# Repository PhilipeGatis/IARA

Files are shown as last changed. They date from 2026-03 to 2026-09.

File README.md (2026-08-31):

<p align="center">
  IARA Logo
</p>

# IARA

**Automated Water Change, Fertilization & Filtration System for Aquariums** — ESP32 firmware.

*Named after Iara, the freshwater spirit from Brazilian folklore.*



> 🇧🇷 Leia em português: [README.pt-BR.md](README.pt-BR.md)
>
> 🇯🇵 日本語で読む: [README.ja.md](README.ja.md)

---

## 📖 About

**IARA** is a complete embedded system for planted aquarium automation. It manages:

- **Water Change (TPA)** — automated drain & refill with a 6-state state machine.
- **Fertilization** — scheduled dosing via peristaltic pumps with stock tracking.
- **Filtration** — canister on/off control through an SSR relay (AC power), with a timed pause for feeding.
- **Safety** — continuous sensor monitoring, watchdog timer, and emergency shutdown mode.

The firmware runs on an **ESP32 DevKit V1** and features an **embedded web dashboard** (React + Vite served via LittleFS), **color TFT display (ST7735)**, **DS3231 RTC clock**, and a **serial command interface**.
You can easily access the web interface on your local network by navigating to **http://iara.local** (via mDNS), without needing to find the ESP32's IP address.

---

## 📱 Interface

The dashboard is served from the ESP32 itself over LittleFS — no cloud, no
account, no external dependency. It is mobile-first, since the phone is what
you have in your hand when you are standing at the tank.

| | | |
|---|---|---|
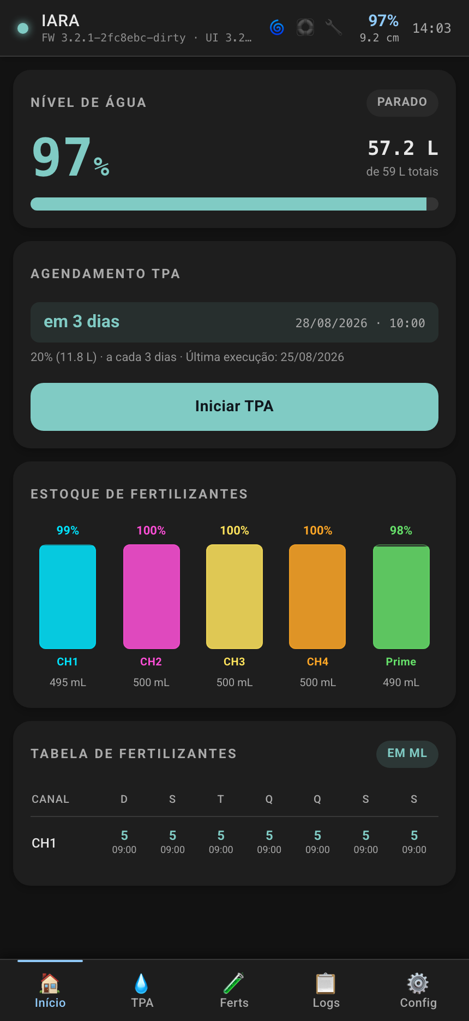
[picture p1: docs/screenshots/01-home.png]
Home
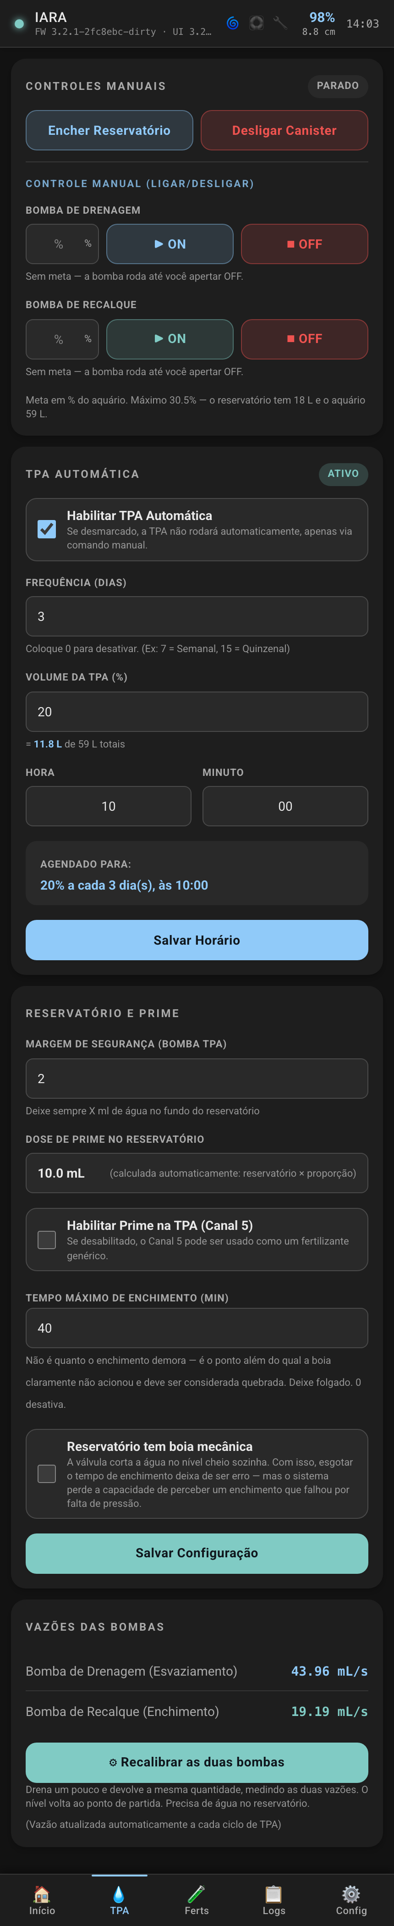
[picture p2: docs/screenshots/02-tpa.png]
Water change
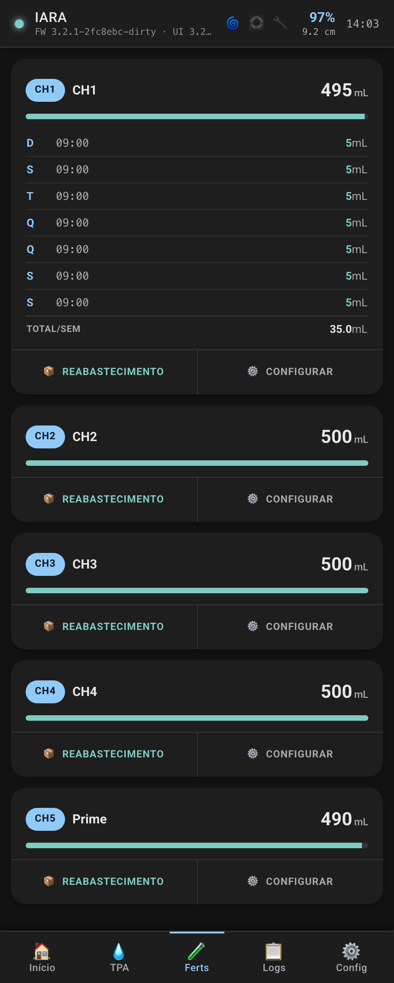
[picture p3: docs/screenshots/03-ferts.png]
Fertilizers
|  |  |  |
| **Home** — level, next change, fertilizer stock | **Water change** — manual pumps, schedule, calibration | **Fertilizers** — per-channel weekly dosing |

| | |
|---|---|
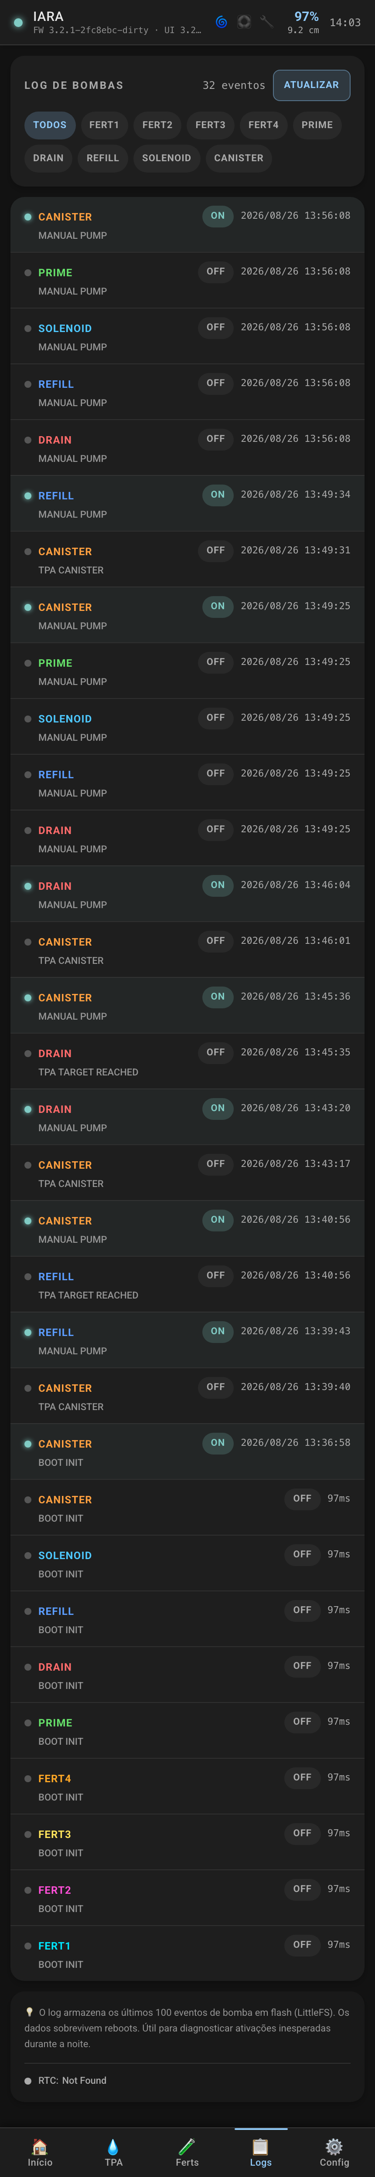
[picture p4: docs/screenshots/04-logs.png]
Logs
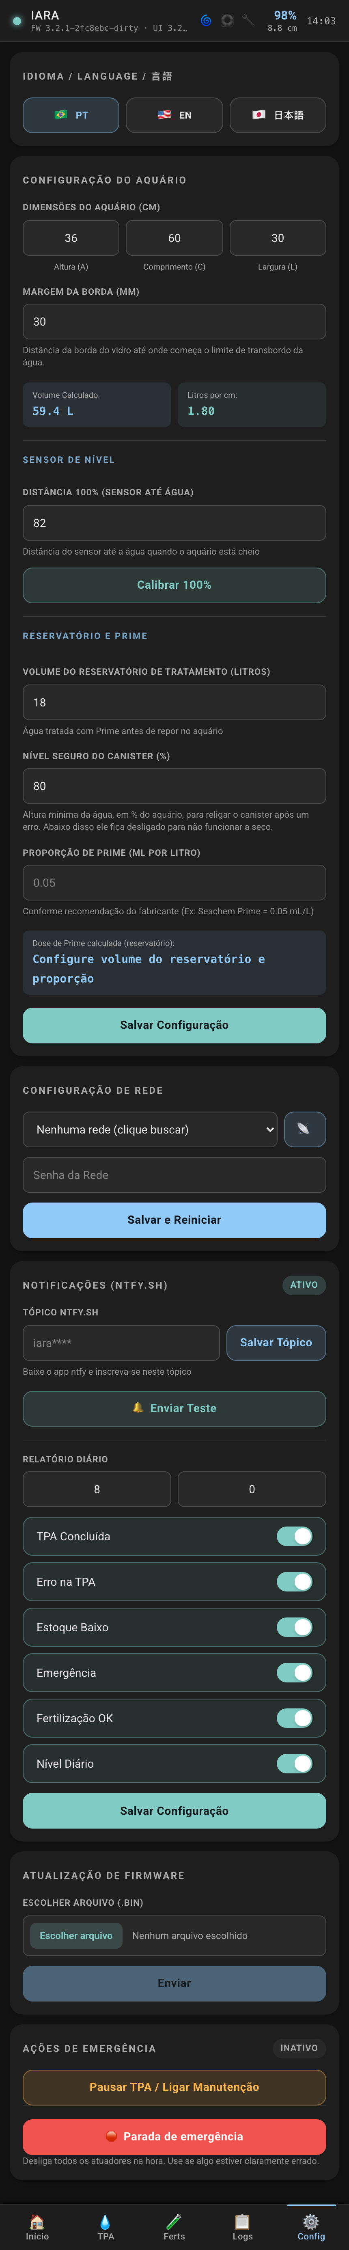
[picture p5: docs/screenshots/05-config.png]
Config
|  |  |
| **Logs** — every pump activation with its reason | **Config** — geometry, sensor, network, notifications, OTA |

---

## 📚 Additional Documentation

The project includes detailed hardware documentation in the following files:

| Document | Description |
|---|---|
| [`BOM.en.md`](BOM.en.md) | **Bill of Materials** — complete list of all components required for assembly, organized by layer (AC, DC, actuators, sensors, protection, and connectors), with specifications and quantities. |
| [`HARDWARE.en.md`](HARDWARE.en.md) | **Hardware Architecture** — detailed technical documentation with wiring diagrams for each layer (AC input, DC bus, and peripherals), including noise protection schemes, the 10 kΩ pull-up on the ultrasonic UART line, and safety implementation notes. |
| [`3d_models/`](3d_models/) | **3D Models (OpenSCAD)** — parametric electronics enclosure (`electronics_enclosure.scad`) with full module layout, dosing pump supports (`dosing_pump_support.scad` / `dosing_pump_single.scad`), and drill test plate for verification. |

---

## 🏗️ Firmware Architecture

```
main.cpp               ← Main orchestrator
├── SafetyWatchdog      ← Sensors + emergency + maintenance mode
├── TimeManager         ← DS3231 RTC + NTP sync
├── FertManager         ← Dosing + NVS dedup + stock tracking
├── WaterManager        ← Water change state machine (6 states)
├── DisplayManager      ← TFT ST7735 128×160 (SPI)
└── WebManager          ← Embedded web dashboard + serial interface
```

### Safety-First Loop

```cpp
loop() {
    safety.update();          // 🔴 Highest priority
    if (emergency) return;
    timeMgr.update();
    commands.process();
    schedules.check();
    waterMgr.update();        // Water change state machine
    telemetry.send();
}
```

### 🔄 Water Change (TPA) Flow

The TPA is a 6-state state machine that runs non-blocking inside the main loop. Each state has a configurable timeout for safety.

```mermaid
stateDiagram-v2
    [*] --> FILLING_RESERVOIR: startTPA()
    FILLING_RESERVOIR --> DOSING_PRIME: float switch
    DOSING_PRIME --> CANISTER_OFF: 2s mix
    CANISTER_OFF --> DRAINING: 3s settle
    DRAINING --> REFILLING: level reached
    REFILLING --> CANISTER_ON: level reached
    CANISTER_ON --> [*]: COMPLETE

    DRAINING --> ERROR: timeout
    FILLING_RESERVOIR --> ERROR: timeout
    REFILLING --> ERROR: timeout
    ERROR --> [*]: check level → canister ON/OFF
```

| Step | State | What happens |
|---|---|---|
| 1 | **FILLING_RESERVOIR** | Solenoid valve opens to fill the reservoir with tap water. The float switch closes it when full. If the reservoir is already full the step is skipped without opening the valve. |
| 2 | **DOSING_PRIME** | Peristaltic pump doses dechlorinator (Prime) into the reservoir. Waits 2 seconds for mixing. Stock is deducted and saved to NVS. |
| 3 | **CANISTER_OFF** | Canister filter is turned off (SSR relay HIGH). Waits 3 seconds for the water to settle so the ultrasonic gets a stable reading. |
| 4 | **DRAINING** | Drain pump turns on. The ultrasonic monitors the level and the pump runs until the target is reached. Flow rate is measured for auto-calibration. |
| 5 | **REFILLING** | Refill pump turns on, pumping treated water from the reservoir into the aquarium. When the original level appears reached the pump **pauses for 3 seconds** and confirms on a settled surface — inflow beside the sensor reads as a level higher than the tank holds. If the calm reading is still short, it resumes. A reed switch in series with the MOSFET channel signal cuts the pump in hardware should max level be reached. Flow rate is measured for calibration. |
| 6 | **CANISTER_ON** | Canister filter is turned back on. **TPA cycle complete.** Calibrated flow rates are saved to NVS for the next TPA. |

> **Why the reservoir comes first:** everything that can fail there — no mains pressure, a stuck float, a dead solenoid — fails while the aquarium is still full and the filter still running. Draining first would leave the same failure with a low tank, a stopped canister and no treated water to put back.

**Safety at every step:**
- Each state has a **dynamic timeout** calculated from calibrated flow rates (`volume / flow × 1.5`). First TPA uses safe defaults: **30s drain, 15s refill**.
- A **reed switch** in series with the signal wire between GPIO33 and MOSFET module input IN7 cuts the refill pump at max level, **independently of the firmware** — it works with the ESP32 hung or the ultrasonic silent. See [`HARDWARE.en.md`](HARDWARE.en.md).
- **Emergency abort** at any point turns off all actuators and restores the canister filter.
- **On error**, the system checks the water level via ultrasonic before turning the canister back on. If the level is too low (e.g. error during drain), the canister **stays OFF** to avoid running dry and damaging the pump.

---

## 🔌 Hardware Overview

### Main Connections

```mermaid
graph LR
  subgraph Power [⚡ 12V & 5V]
    PSU[12V PSU] -->|12V| MOSFET[8-Channel MOSFET Module]
    PSU -->|12V| LM2596[LM2596 Step Down]
    LM2596 -->|5V| Cap[Electrolytic Capacitor]
    Cap -->|5V| ESP32[ESP32 VIN]
    ESP32 -->|3.3V VCC| SENS[Sensors]
  end

  subgraph Signals [🎮 ESP32 Signals]
    ESP32 -->|D21 SDA, D22 SCL| I2C[RTC DS3231]
    ESP32 -->|SPI D15,16,17,23| TFT[TFT Display ST7735]
    ESP32 -->|D12, D13, D14, D25-D27, D32, D33| MOSFET
    ESP32 -->|D2| SSR[Omron SSR]
    ESP32 ---|D34 RX| Ultra[Ultrasonic A02YYUW UART]
    ESP32 ---|D5| Button[Panel button]
    ESP32 ---|D19| Float[Float Switch]
  end

  MOSFET -->|OUT 1–5| Peristaltic[5x Peristaltic Pumps]
  MOSFET -->|OUT 6| Drain[Drain Pump]
  MOSFET -->|OUT 7| Refill[Refill Pump]
  MOSFET -->|OUT 8| Solenoid[Solenoid Valve]
```

> For detailed wiring diagrams and protection notes (flyback diodes, star GND), see [`HARDWARE.en.md`](HARDWARE.en.md).
>
> For the complete component list and quantities, see [`BOM.en.md`](BOM.en.md).

### ESP32 GPIO Connection Diagram

| GPIO | Function | Component | Direction | Protocol |
|---|---|---|---|---|
| **D2** | Canister ON/OFF | Omron SSR Relay | Output | Digital |
| **D12** | Fertilizer CH2 | MOSFET channel 2 | Output | Digital |
| **D13** | Fertilizer CH1 | MOSFET channel 1 | Output | Digital |
| **D14** | Fertilizer CH3 | MOSFET channel 3 | Output | Digital |
| **D15** | TFT CS | ST7735 Display (CS) | Output | SPI (CS) |
| **D16** | TFT SCK | ST7735 Display (SCK) | Output | SPI (SCK) |
| **D17** | TFT A0 (Data/Command) | ST7735 Display (A0) | Output | SPI (DC) |
| **D5** | Navigation button | Push/Tactile Button (Panel) | Input (PULLUP) | Digital |
| **D18** | Ultrasonic control lead | A02YYUW (control wire) | Output | Held idle-high |
| **D19** | Reservoir float | Horizontal Float Switch | Input (PULLUP) | Digital |
| **D21** | SDA | DS3231 RTC | Bidirectional | I2C |
| **D22** | SCL | DS3231 RTC | Bidirectional | I2C |
| **D23** | TFT SDA (Data) | ST7735 Display (SDA) | Output | SPI (MOSI) |
| **D25** | Drain pump | MOSFET channel 6 | Output | Digital |
| **D26** | Prime (dechlorinator) | MOSFET channel 5 | Output | Digital |
| **D27** | Fertilizer CH4 | MOSFET channel 4 | Output | Digital |
| **D32** | Solenoid valve | MOSFET channel 8 | Output | Digital |
| **D33** | Refill pump | MOSFET channel 7 | Output | Digital |
| **D34** | Ultrasonic UART RX | A02YYUW | Input | Digital (Connect to Sensor TX) |
| **VIN** | 5V Power | LM2596 step-down | — | Power |
| **EN** | Shared reset | ST7735 Display (RESET) | — | Reset |
| **3.3V** | Backlight | ST7735 Display (LED) | — | Power |

---

## 🛡️ Safety & Reliability

The system is designed with a **safety-first** approach to prevent flooding, equipment damage, and fish loss.

### Software Protections

| Protection | Description |
|---|---|
| **Max-level interlock (hardware)** | Reed switch in series with the refill channel's signal. Cuts the pump without involving the firmware. It is the only protection that survives a hung ESP32. |
| **SafetyWatchdog** | Runs at highest priority every loop iteration. Monitors the ultrasonic, detects emergency conditions, and shuts down all actuators. Counts 10 consecutive overflow readings before flagging, to prevent false positives. |
| **Non-blocking loops** | All wait states (canister settle, prime mixing) use `millis()` instead of `delay()`, so the safety watchdog keeps running during waits. |
| **State machine timeouts** | Each TPA state (`DRAINING`, `FILLING`, `REFILLING`) has a configurable timeout. Exceeding it triggers an error state and shuts down all actuators. |
| **NVS deduplication** | Prevents double-dosing fertilizers on the same day, even after unexpected reboots. |
| **Emergency shutdown** | `emergency_stop` command turns off ALL actuators immediately. |
| **CPU throttle** | Main loop runs at ~100 Hz (`delay(10)`), preventing overheating and leaving CPU headroom for WiFi/TCP stack. |
| **Pump auto-calibration** | Flow rates measured inline during TPA (Δlevel × litersPerCm / Δtime). Dynamic timeouts = `(volume / flow) × 1.5`. First TPA uses safe 30s/15s defaults. |
| **Mandatory TPA config** | TPA will not start unless all required parameters are configured: aquarium dimensions, reservoir volume, drain %, and canister safe level %. Prevents running with invalid/default values. |
| **Canister safe level (%)** | Configurable minimum water level (as % of aquarium height) required to safely turn the canister back on after a TPA error. If the water is below this threshold (e.g. error during drain), the canister stays OFF to prevent running dry. |

### Hardware Recommendations

| Protection | Description |
|---|---|
| **Max-level reed switch** | NO (normally open) reed with a magnet held at the max water level by an EVA float, wired in series with the **signal** wire between GPIO33 and MOSFET input IN7 — never in series with the pump's power. Cuts the pump physically if water rises too high, independent of firmware. See [`HARDWARE.en.md`](HARDWARE.en.md). |
| **Flyback diodes** | FR154 on pumps, 1N5822 on solenoid — absorb voltage spikes from inductive loads. |
| **Decoupling capacitors** | 1000µF near ESP32, 470µF near MOSFET module — absorb brownout transients. |
| **Direct 3.3V UART** | A02YYUW powered at 3.3V connects directly to ESP32 without voltage dividers. |
| **Siphon break (Drain)** | Wire a solenoid valve in parallel with the drain pump (requires its own flyback diode) or make a small breather hole in the hose inside the aquarium to prevent water from continuing to drain by gravity after the pump turns off. |

---

## 📲 Push Notifications

IARA sends real-time push notifications to your phone via [ntfy.sh](https://ntfy.sh/). Each notification type can be individually enabled or disabled via the dashboard.

### Notification Types

| Type | Trigger | Example Message |
|---|---|---|
| **TPA Complete** | Water change finished successfully | `✅ TPA completed successfully` |
| **TPA Error** | Timeout or failure during TPA | `⚠️ Drain timeout \| Canister: OFF (nivel 45%, min: 60%)` |
| **Fert Low Stock** | Fertilizer stock below threshold | `⚠️ CH1 Potássio: 15 mL remaining (threshold: 50 mL)` |
| **Emergency** | Emergency shutdown triggered | `🚨 Emergency shutdown activated!` |
| **Fert Complete** | Fertilizer dose completed | `💧 CH2 dosed 5.0 mL` |
| **Daily Level** | Scheduled daily water level report | `📊 Water level: 12.3 cm` |

### Rate Limiting

| Parameter | Value |
|---|---|
| Cooldown per type | 5 minutes (same type won't fire twice) |
| Max per day | 20 notifications total |
| Daily counter reset | Midnight (auto) |

### Setup

1. Download the **ntfy** app on your phone (iOS/Android)
2. Tap "+" to "Subscribe to topic"
3. Enter the topic generated by IARA (shown on the aquarium display or Dashboard) and you're done!
3. Or set the topic from the IARA dashboard (`Notifications → ntfy.sh Topic`), or via API:
   ```bash
   curl -X POST http://<ESP32_IP>/api/notify/key -d '{"topic":"YOUR_TOPIC"}'
   ```
4. Enable/disable specific notification types via the dashboard

---

## ⚙️ System Configuration

Before the first TPA can run, the system requires all safety-critical parameters to be configured. This ensures the water change operates safely for your specific aquarium setup.

### Required Parameters (Mandatory for TPA)

| Parameter | API Field | Description |
|---|---|---|
| **Aquarium Height** | `aqHeight` | Internal height in cm |
| **Aquarium Length** | `aqLength` | Internal length in cm |
| **Aquarium Width** | `aqWidth` | Internal width in cm |
| **Reservoir Volume** | `reservoirVolume` | Reservoir capacity in liters |
| **TPA Drain %** | `tpaPercent` | Percentage of aquarium volume to drain (e.g. 30%) |
| **Canister Safe Level %** | `canisterSafePct` | Minimum water % required to safely turn canister ON (e.g. 60%) |

> [!IMPORTANT]
> TPA will **not start** until all 6 parameters above are configured. The dashboard shows `tpaConfigReady: true/false` to indicate readiness.

### Optional Parameters

| Parameter | API Field | Description |
|---|---|---|
| **Water Margin** | `aqMarginMm` | Distance from top edge to the overflow limit (mm) |
| **Prime Ratio** | `primeRatio` | mL of dechlorinator per liter of water |
| **Reservoir Safety** | `reservoirSafetyML` | Minimum mL to keep in reservoir for pump safety |
| **TPA Interval** | `tpaInterval` | Days between automatic TPAs (e.g. 7) |
| **TPA Schedule** | `tpaHour`, `tpaMinute` | Time of day for automatic TPA |

### Configuration via API

**Aquarium dimensions:**
```bash
curl -X POST http://<ESP32_IP>/api/config/aquarium \
  -H "Content-Type: application/json" \
  -d '{"aqHeight":45, "aqLength":90, "aqWidth":40, "aqMarginMm":30, "reservoirVolume":20, "primeRatio":0.025}'
```

**TPA schedule + canister safety:**
```bash
curl -X POST http://<ESP32_IP>/api/schedule \
  -H "Content-Type: application/json" \
  -d '{"tpaInterval":7, "tpaHour":10, "tpaMinute":0, "tpaPercent":30, "canisterSafePct":60}'
```

### How Configuration is Stored

All parameters are persisted in **NVS (Non-Volatile Storage)** and survive reboots and power cycles. Configuration can be set via:

1. **Web Dashboard** — React SPA with forms for all parameters
2. **REST API** — JSON endpoints for programmatic access
3. **Serial Commands** — USB serial for debugging and initial setup

### Derived Values (Auto-Calculated)

| Value | Formula | Purpose |
|---|---|---|
| **Aquarium Volume** | `(Height - Margin) × Length × Width / 1000` | Total water volume in liters |
| **Liters per cm** | `Length × Width / 1000` | Volume change per cm of water level |
| **Prime dose** | `Reservoir Volume × Prime Ratio` | Auto-calculated dechlorinator dose |
| **Drain cm** | `(Volume × TPA%) / Liters per cm` | Calculated at TPA start |
| **Canister safe cm** | `EffHeight × (100 - SafePct) / 100` | Ultrasonic distance threshold |
| **Dynamic timeouts** | `(Volume / Flow) × 1.5` | Calculated from calibrated flow rates |

---

---

## 🧪 Testing

### Run unit tests (no hardware required)

```bash
pio test -e native
```

### Generate coverage report

```bash
pio test -e coverage && ./scripts/coverage.sh
open coverage/index.html
```

### Test Suites

| Suite | Tests | Coverage |
|---|---|---|
| `test_fert_manager` | 13 | NVS dedup, stock, GPIO, persistence |
| `test_safety_watchdog` | 14 | Sensors, emergency, maintenance |
| `test_water_manager` | 23 | Full water change state machine + calibration |
| `test_time_manager` | 15 | DateTime, scheduling, formatting |
| `test_notify_manager` | 10 | Notifications, formatting |

### 📊 Code Coverage

| File | Coverage |
|---|---|
| `WaterManager.cpp` | 92% |
| `SafetyWatchdog.cpp` | 81% |
| `FertManager.cpp` | 75% |
| `NotifyManager.cpp` | 43% |
| **Total** | **75%** |

> 75 native unit tests running in CI on every commit.

---

## 🚀 Build & Deploy

### First-time setup — WiFi credentials

Credentials live outside the repository. Before the first build:

```bash
cp secrets.ini.example secrets.ini
# then edit secrets.ini with your network's SSID and password
```

`secrets.ini` is gitignored, so it never reaches the repository. The build fails
without it.

### Build and flash firmware

```bash
# Build firmware
pio run

# Flash to ESP32
pio run --target upload

# Serial monitor
pio device monitor
```

### Full deploy (Frontend + Firmware)

The `Makefile` automates the full workflow:

```bash
# All at once: build React → upload LittleFS → flash firmware
make all

# Or individual steps:
make build-front     # Build React app (Vite)
make upload-fs       # Upload static files to LittleFS
make upload-fw       # Build and flash C++ firmware
make monitor         # Open serial monitor
make clean           # Clean all builds
```

### Frontend (Web Dashboard)

The web dashboard is a React + Vite + Tailwind CSS SPA located in `frontend/`. After building, static files are copied to `data/` and uploaded to the ESP32 via LittleFS.

```bash
cd frontend && npm install && npm run build
```

---

## ⌨️ Serial Commands

| Command | Description |
|---|---|
| `help` | List available commands |
| `status` | Current system state |
| `tpa` | Start manual water change |
| `abort` | Abort water change in progress |
| `maint` | Toggle maintenance mode (30 min) |
| `fert_time HH MM` | Set fertilization time |
| `tpa_interval DAYS` | Set days between automatic water changes (0 = off) |
| `dose CH ML` | Set dose for channel CH (1–5) |
| `reset_stock CH ML` | Reset stock for channel CH |
| `set_drain CM` | Set drain target level |
| `set_refill CM` | Set refill target level |
| `emergency_stop` | Shut down ALL actuators |

---

## 📁 Project Structure

```
├── BOM.md                    # Bill of Materials (pt-BR)
├── BOM.en.md                 # Bill of Materials (en-US)
├── BOM.ja.md                 # Bill of Materials (ja-JP)
├── HARDWARE.md               # Hardware architecture (pt-BR)
├── 3d_models/                # 3D models for printing and laser cutting
│   ├── electronics_enclosure.scad  # Electronics enclosure (base + lid)
│   ├── dosing_pump_support.scad    # 8-pump dosing support
│   └── dosing_pump_single.scad     # Single pump support
├── HARDWARE.en.md            # Hardware architecture (en-US)
├── HARDWARE.ja.md            # Hardware architecture (ja-JP)
├── README.md                 # Documentation (en-US) — default
├── README.pt-BR.md           # Documentation (pt-BR)
├── README.ja.md              # Documentation (ja-JP)
├── Makefile                  # Automation: build frontend + upload
├── platformio.ini            # Environments: esp32dev, native, coverage
├── include/
│   ├── Config.h              # Pins, timeouts, constants
│   ├── SafetyWatchdog.h
│   ├── TimeManager.h
│   ├── FertManager.h
│   ├── WaterManager.h
│   ├── WebManager.h
│   └── web_dashboard.h       # Dashboard HTML/CSS/JS (fallback)
├── src/
│   ├── main.cpp              # Setup + loop
│   ├── SafetyWatchdog.cpp
│   ├── TimeManager.cpp
│   ├── FertManager.cpp
│   ├── WaterManager.cpp
│   └── WebManager.cpp
├── frontend/                 # React + Vite + Tailwind dashboard
│   ├── src/
│   └── vite.config.ts
├── data/                     # Static files (frontend build → LittleFS)
├── test/
│   ├── mocks/                # Arduino mock layer (GPIO, NVS, RTC)
│   ├── test_fert_manager/
│   ├── test_safety_watchdog/
│   ├── test_water_manager/
│   └── test_time_manager/
├── scripts/
│   └── coverage.sh           # lcov coverage report generator
└── .github/workflows/
    └── test.yml              # CI: tests on every commit
```

---

## ☕ Support

If you find this project helpful, consider buying me a coffee!

<a href="https://buymeacoffee.com/iara.automatedwaterchange" target="_blank">
  Buy Me A Coffee
</a>

---

## 📜 License

MIT

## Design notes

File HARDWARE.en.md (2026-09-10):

# Hardware Architecture Documentation: Aquarium Management System

## 📋 Overview

The system uses a **Defense in Depth** topology with noise filtering at the input (AC), stabilization on the main bus (DC), and inductive spike suppression at the edge (Actuators).

```
┌─────────────────────┐     ┌─────────────────────┐     ┌─────────────────────┐
│  LAYER 1: AC        │ ──► │  LAYER 2: DC        │ ──► │  LAYER 3: EDGE      │
│  Input/Protection   │     │  Bus/Logic          │     │  Peripherals/Suppr. │
│                     │     │                     │     │                     │
│  • AC Fuse          │     │  • 12.53V PSU       │     │  • Flyback Diodes   │
│  • NTC (Inrush)     │     │  • LM2596 → 5.1V    │     │  • Decoupling Caps  │
│  • EMI Filter (Y)   │     │  • Cap Bank         │     │  • Sensors (GX12)   │
│  • Canister Relay   │     │  • 8-Ch MOSFET      │     │  • Pumps + Valve    │
└─────────────────────┘     └─────────────────────┘     └─────────────────────┘
```

---

## ⚡ Layer 1: AC Input & Protection (Infrastructure)

The power input architecture focuses on simplicity and maximum electrical safety, delegating heavy filtering (like EMI filter and NTC/Inrush limits) to the professional circuits already built into the Switching Power Supply.

### Components

| Component | Function |
|---|---|
| **AC Glass Fuse** (3A to 5A) | Mandatory item: Protection against hard short circuits and fire risks |
| **SSR Relay Module 1CH** | Independent control via ESP32 for the Canister filter (AC) |

### Wiring Diagram

<p align="center">
  AC input: IEC C14 inlet splitting earth, neutral and live; live passes through the fuse and the SSR relay before the canister socket.
</p>

---

## 🔋 Layer 2: DC Bus & Logic (Distribution)

Responsible for converting power to logic levels and maintaining ESP32 stability during heavy load switching.

### Components

| Component | Function |
|---|---|
| **180W Switching PSU** | Adjusted to 12.53V |
| **T5AL250V Fuse** | Physical firewall for 8 pumps and sensors |
| **LM2596** | Step-down adjusted to 5.1V (ESP32 power) |
| **1× 470µF 16V** | In parallel at 12V MOSFET input (Prevents voltage dips on pump startup) |
| **4× 1000µF 10V** | In parallel at 5V output (Acts as a "UPS" for ESP32 to withstand line fluctuations and spikes) |
| **1× 1000µF 10V** | Directly across the devkit's 3V3 and GND pins. The 5V bank does **not** cover this node — see the warning below |

### Wiring Diagram

<p align="center">
  DC bus: the 12.53 volt supply feeding the LM2596 and the MOSFET module, with every power return starred at the V minus terminal.
</p>

> [!IMPORTANT]
> **POWER GND — star at the PSU**: **Power** negative references (MOSFET module, LM2596, pumps, solenoid) must return directly to the PSU V− terminal, to avoid ground loops.

> [!CAUTION]
> **SIGNAL GND — the opposite rule**: The return (GND) of the **sensors** — float switch and ultrasonic — must go to the **ESP32 GND pin**, and **never** straight to the PSU terminal.
>
> The ESP32 measures every input relative to *its own* GND pin. A sensor referenced to the PSU terminal hands the GPIO the potential difference between those two points. During pump startup that difference exceeds **1 V negative** — far beyond the ESP32's −0.3 V absolute minimum — and the damage accumulates until the pin fails open.
>
> This is exactly how GPIO5 and GPIO19 burned out. See [`PROTECAO_ELETRICA.md`](PROTECAO_ELETRICA.md) (Portuguese only).

> [!IMPORTANT]
> **3V3 decoupling — the 5V bank does not cover this node.**
>
> The 4× 1000 µF sit **upstream** of the devkit's AMS1117, which is a series regulator. Charge cannot cross it faster than its control loop allows, and for the tens of microseconds it takes to answer a current step, the only source for 3V3 is the board's own output capacitor — 10 to 22 µF on a DevKit V1.
>
> The ESP32's brownout detector watches **VDD3P3**. That is why the board kept resetting with `ESP_RST_BROWNOUT` at irregular intervals, with the tank idle and no pump running, while the entire 5V bus stayed charged and never dipped. A WiFi transmit burst is the only load here that moves without anyone asking.
>
> A **1000 µF 10 V** electrolytic soldered straight across the devkit's **3V3 and GND pins** — short leads, negative stripe to GND — ended the resets. The rule that explains it: decoupling only helps the node it is attached to. Same reason the ultrasonic sensor gets its own pair of capacitors at its connector rather than on the board.

---

## 🌊 Layer 3: Peripherals & Suppression (Edge)

Responsible for mitigating inductive noise (Flyback) and stabilizing sensor readings on long cables (1.2m).

### Components

| Component | Application | Qty |
|---|---|---|
| **FR154 Diodes** (Fast Recovery) | Refill and Drain Pumps | 2 |
| **FR154 Diodes** (Fast Recovery) | Peristaltic Pumps (4 Fert + 1 Prime) | 5 |
| **1N5822 Diode** (Schottky) | Solenoid Valve (Channel 8) | 1 |
| **10µF / 22µF 50V Capacitors** | Sensor decoupling at cable ends (GX12) | — |

> [!NOTE]
> **Total: 8 flyback diodes** — one per motor channel (7× FR154 + 1× 1N5822). All installed at the cable end, next to the motor.

### Wiring Diagram — Actuators

<p align="center">
  MOSFET channel and bus GND reaching the pump over 1.2 metre wires, with the flyback diode fitted at the motor.
</p>

> [!CAUTION]
> **Flyback Diodes**: Must be installed at the **cable end** (next to the motor) to prevent the 1.2m cable from radiating noise like an antenna.

### Wiring Diagram — Ultrasonic Sensor (A02YYUW, UART)

Waterproof ultrasonic sensor that reports distance over **UART**. No TRIG/ECHO, and no voltage divider needed. It transmits on its own without being commanded: one frame every ~100 ms.

| Wire | Function | Connection | Note |
|---|---|---|---|
| **VCC** (red) | Supply | ESP32 3.3V | ⚠️ Never 5V — see warning below |
| **GND** (black) | Return | **ESP32 GND pin** | ⚠️ Never the PSU terminal |
| **TX** | Sensor data output | GPIO34 (RX2) | Needs a 10kΩ pull-up |
| **RX** | Control input | 3.3V | Unused by the firmware — see note |

> The colors of the two data wires vary between batches; only red and black are consistent. To identify the output, power the sensor and measure: **TX** idles at ~3.3V and shows activity; RX stays inert.

<p align="center">
  A02YYUW ultrasonic sensor wired to the ESP32: VCC at 3.3 volts, TX on GPIO34 with a 10 kilo-ohm pull-up, RX tied to 3.3 volts and GND on the board pin.
</p>

> [!WARNING]
> **Power it at 3.3V, never 5V.** The A02YYUW accepts 3.3–5V, but its output logic level follows VCC. At 5V the TX line would drive 5V into GPIO34 and permanently damage it. Running at 3.3V is precisely what makes the direct connection possible without a divider.

> [!IMPORTANT]
> **10kΩ pull-up between GPIO34 and 3.3V.** GPIO34 is input-only and has **no internal pull-up**. Without the external resistor, a loose cable or unpowered sensor leaves the line floating and the firmware reads noise as data. With the pull-up the line idles high — the UART idle state — and missing data becomes a clean failure, caught by the 2 s timeout in `SafetyWatchdog::readUltrasonic()`.

> [!NOTE]
> **The control wire (sensor RX) is unused.** Nothing in the firmware writes to `Serial2`; the sensor transmits on its own. That wire should go to **3.3V** to keep continuous-transmission mode — what must be avoided is leaving it floating.
>
> That wire sits on **GPIO18**. Nothing in the firmware writes to `Serial2`, but the pin stays declared as the UART TX precisely so the line is held idle-high, which is what the sensor needs to stay in continuous mode.

> [!TIP]
> **Protocol:** 9600 baud, 8N1. 4-byte frame — `0xFF`, `DataH`, `DataL`, `Checksum`, where distance is in **millimeters** (`(DataH << 8) | DataL`) and the checksum is `(0xFF + DataH + DataL) & 0xFF`. The firmware discards frames with an invalid checksum and applies a 5-sample median filter.

> [!CAUTION]
> **Local decoupling.** At 3.3V the sensor runs at the bottom of its range, which makes it sensitive to the voltage sag when pumps start — the symptom is corrupted readings during exactly the drain and refill steps. Fit **100 µF + 100 nF at the sensor connector**, not on the board. See [`PROTECAO_ELETRICA.md`](PROTECAO_ELETRICA.md) (Portuguese only).

### Wiring Diagram — Max-Level Interlock (Reed Switch)

#### Why the interlock is on the refill pump, not the solenoid

At first glance the solenoid looks like the obvious target: it is fed from the water mains and on its own would flood the house. But it **already has a mechanical float valve** in the reservoir — a valve that physically shuts the flow when the water rises, with no electronics involved. Same idea as a cistern ballcock.

The refill pump has no such thing and cannot have one: it pushes water *into* the aquarium, and no mechanical valve on the discharge side stops a pump. If it does not stop, the water goes on the floor. So the reed protects the channel that had nothing.

Water interlocks, strongest first:

| Actuator | Physical stop | Electrical stop | Firmware |
|---|---|---|---|
| Solenoid (CH8) | **Mechanical float valve in the reservoir** | — | Float switch on GPIO19 + 8-minute timeout |
| Refill pump (CH7) | — (not possible) | **Reed in series with the pump's +12 V** | Ultrasonic + flow-sized timeout |

The max-level cutoff **does not go through the firmware**. It is a reed switch in series with the refill pump's **+12 V** wire. If the water reaches max level the contact opens, the pump loses power and stops — even with the ESP32 hung, rebooting, the ultrasonic silent, **or the MOSFET shorted**.

That last case is why the reed sits in the power line and not in the signal. The MOSFETs on these modules fail shorted drain to source, and in that failure cutting the gate does nothing: the pump keeps running, and neither the firmware nor a reed on the signal can stop it.

Assembly: **NO** (normally open) reed with a magnet held nearby by an EVA float, out of the water. At normal level the magnet is present and the contact closed. As the water rises, the float carries the magnet away and the contact opens.

| Situation | Magnet | Reed | 12 V | Pump |
|---|---|---|---|---|
| Normal level | present | closed | passes | may run |
| Max level | away | open | broken | **stopped** |
| Broken wire | — | — | broken | **stopped** |
| MOSFET shorted | away | open | broken | **stopped** |

<p align="center">
  Normally-open reed switch in series with the refill pump's plus 12 volts, and the GPIO33 signal reaching IN7 with a 1 kilo-ohm resistor and a 100 nanofarad capacitor to module GND.
</p>

> [!CAUTION]
> **The 1 kΩ resistor still applies, now for a different reason.** With the reed out of the signal wire that line is never open in operation — but GPIO33 floats during the ESP32's boot and reset. The MOSFET input works by stored charge: without the resistor, the floating gate holds its charge and can keep the MOSFET partially conducting.
>
> Before building, measure the resistance between IN7 and the module GND. If it already reads between 10 kΩ and 100 kΩ, the module has its own pull-down and the external resistor is unnecessary.

> [!WARNING]
> **The reed may sit in the power line only because of this pump.** Reed contacts are rated for 0.5–1 A and 10 W. The pump in this project is 12 V, 5 W, 400 mA maximum, which puts 4.8 W on the contact — a little over 2× margin.
>
> Swap in a larger pump and that stops being true. With several amps at startup the contact arcs and eventually welds closed, a silent failure that voids the interlock. In that case the reed drives a **relay coil** instead (tens of mA), and the relay contact, rated for the load, carries the pump.

> [!CAUTION]
> **What hurts the contact is closing, not opening.** The pump is brushless with an epoxy-sealed board, meaning an input capacitor. A discharged capacitor looks like a short the instant the contact closes, and that surge is what welds reeds. Breaking 400 mA is uneventful.
>
> In practice the risk is small: after a cutoff the pump stops on the timeout, and the water only falls again through evaporation, hours later, with everything already off. The bad case is the float bobbing on the surface with the pump running, chattering the contact under load. During the continuity test, confirm the transition is **clean**, with no chatter near the trip point.

> [!TIP]
> **Test the release distance before sealing the assembly.** A reed has hysteresis: it closes at one distance and only opens at a larger one. With the multimeter on continuity, pull the magnet away until the contact opens and note the distance — the float's travel must be 2 to 3 times that value. Also confirm it does not close again at any intermediate position along the travel.

> [!IMPORTANT]
> **The firmware cannot see the reed, but it can see its effect.** No signal wire comes back from the contact, so the cutoff itself is invisible. What `_handleRefilling()` watches is the **level moving**: with the pump commanded, the water has to rise at the calibrated rate (`_refillFlowLPM / _litersPerCm`). If it does not cover at least 35% of that in 30 s, the state machine stops and reaches `ERROR` in about 50 s instead of burning the 10-minute timeout.
>
> The same check covers what the reed is not: a dead pump, a kinked hose, an empty reservoir, and — the case that motivated it — a **frozen ultrasonic reading**. A sensor that goes quiet already raises an error through `areSensorsConnected()`; one that keeps answering with a stale number is indistinguishable from a tank that stopped filling, and until now the pump ran to the timeout against it.
>
> **GPIO4**, previously the XKC-Y25 capacitive sensor (never installed, dropped from the project), now carries the display's SDA line. The free pin today is **GPIO23**, which SDA vacated. Wiring a second reed to it would give the firmware that visibility back, but requires a code change.

#### Holding the magnet and the reed: the printed seesaw

The part above describes the circuit. The mechanics that carry it are in [`3d_models/reed_level_seesaw.scad`](3d_models/reed_level_seesaw.scad).

It is a seesaw resting on the glass rim. The inner arm ends in a tray where a block of foam is glued; the outer arm carries the 6 × 2 mm magnet **lying flat** on a horizontal pad. The reed lives inside a 5 mm acrylic tube that threads through two fingers growing out of the pivot ears. No part of the circuit touches the water.

| | |
|---|---|
| Glass | 4.9 mm |
| Magnet travel | 23.3 mm |
| Field at the reed — closed / open | ~43 / ~2.4 gauss |
| Highest point above the rim | 45.5 mm |
| Printed parts | 4 |

> [!IMPORTANT]
> **The reed is not above the magnet, and that is not an oversight.** A magnet lying flat throws a vertical field straight above itself, and a reed lying flat cannot see a vertical field — in that position it never closes. The field only turns horizontal on the 54.7° line from the magnet's axis, which is why the contacts sit 9.9 mm to the side and 7 mm above its face. The two dimensions are coupled (`dy = 1.41 × dz`): moving one alone takes the reed off that line. That is why the height is a round hole with no adjustment — the tube is what you adjust, sliding it through the two fingers.

> [!TIP]
> **The magnet arm is what buys release margin, not the float arm.** Magnet travel is `2 × arm_out × sin(15°)`, and the field at the open stop falls with the cube of the distance. Making the float arm longer does the opposite of what it looks like: it is the denominator of the gain, so it trades travel for torque.

The angle between the two arms is chosen on a 12-tooth face coupling, in 30 degree steps. The step is coarse on purpose: the trip level is set by the counterweight, whose range is nearly the whole height of the float. The angle only has to put the float near the surface.

Calibration is the same hysteresis test as the tip above, with one extra step: slide the tube until the contact closes with the lever at the upper stop, and only then confirm it opens at the lower one without closing again anywhere in between.

Printing: four parts in PETG or ASA — PLA absorbs moisture and warps near water. The STLs come already rotated and seated at z = 0, and `reed_seesaw_mesa.stl` carries all four on a 138 × 86 mm plate. Only `bracket` needs support, in two open pockets.

### Wiring Diagram — TFT ST7735 Display (SPI)

1.8" color display, 128×160 pixels. Operates at **3.3V** — incompatible with 5V. Uses software SPI (bit-banging) on custom pins.

| Display Pin | ESP32 Connection | GPIO | Notes |
|---|---|---|---|
| **VCC** | 3.3V | — | ⚠️ Never use 5V |
| **GND** | GND | — | |
| **CS** | D15 | GPIO15 | Chip Select |
| **RESET** | EN pin | — | Hardware reset shared with ESP32 |
| **A0 (DC)** | TX2 | GPIO17 | Data/Command |
| **SDA (MOSI)** | D4 | GPIO4 | SPI Data |
| **SCK** | RX2 | GPIO16 | SPI Clock |
| **LED** | 3.3V | — | Fixed backlight (no free GPIO available) |

<p align="center">
  ST7735 display wired to the ESP32 with six consecutive pins at the bottom of the right-hand header and RESET on the EN pin.
</p>

> [!WARNING]
> The display **RESET** pin must connect to the ESP32 **EN** pin (not a GPIO). This ensures the display resets together with the microcontroller. With EN HIGH (normal operation), the display works normally.

> [!NOTE]
> On the ESP32 DevKit V1 breakout board, **D16** and **D17** are labeled **RX2** and **TX2** respectively. Use your terminal block labels to identify the correct positions.

---

### Wiring Diagram — Reservoir Float Switch

Horizontal float switch that signals "reservoir full". It closes the solenoid during the TPA `FILLING_RESERVOIR` state. The firmware requires 5 consecutive "full" reads (~250 ms debounce) before accepting the signal.

| Pin | Connection | GPIO | Configuration |
|---|---|---|---|
| **Terminal 1** | GPIO19 | GPIO19 | `INPUT_PULLUP` — active LOW |
| **Terminal 2** | **ESP32 GND pin** | — | ⚠️ Never the PSU terminal |

<p align="center">
  Reservoir float switch between GPIO19 and the ESP32's GND pin.
</p>

> [!NOTE]
> The float switch originally used GPIO5, but that pin is an ESP32 strapping pin and suffered interference (~2.5 V at rest). It was moved to GPIO19, which previously drove the panel navigation button.

> [!IMPORTANT]
> **The panel navigation button is on GPIO5** (`PIN_BTN` in `include/Config.h`). It lost GPIO19 to the float switch. GPIO5 is an ESP32 strapping pin, so it must not be held down through power-on; a momentary press at any other time is harmless.

---

## 🛠️ Safe Implementation Notes

1. **AC Connections** — Insulate all 110V/220V solder joints and connections with heat-shrink tubing for maximum safety.

2. **Capacitor Polarity** — Check the negative stripe on every electrolytic: the 1000µF 10V units on the 5.1V bus, and the 1000µF across the devkit's 3V3/GND pins.

3. **Flyback Diodes** — Must be installed at the cable end (next to the motor) to prevent the 1.2m cable from radiating noise like an antenna.

4. **Star GND** — All negative references must return directly to the PSU V− terminal to avoid ground loops.

5. **Siphon Effect (Hydraulics)** — To prevent continuous gravity draining of the aquarium after the drain pump is turned off, wire a solenoid valve in parallel with the drain pump (on the same MOSFET channel, ensuring a flyback diode for each) or make a breather hole in the hose.

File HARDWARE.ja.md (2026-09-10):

# ハードウェアアーキテクチャ資料：水槽管理システム

## 📋 概要

本システムは**多層防御**トポロジーを採用し、入力側（AC）でのノイズフィルタリング、メインバス（DC）での安定化、エッジ側（アクチュエーター）での誘導性スパイク抑制を行います。

```
┌─────────────────────┐     ┌─────────────────────┐     ┌─────────────────────┐
│ レイヤー1: AC        │ ──► │ レイヤー2: DC        │ ──► │ レイヤー3: エッジ    │
│ 入力/保護           │     │ バス/ロジック       │     │ 周辺機器/抑制       │
│                     │     │                     │     │                     │
│ • ACヒューズ        │     │ • 12.53V電源        │     │ • フライバックD     │
│ • NTC（突入電流）   │     │ • LM2596 → 5.1V    │     │ • デカップリングC   │
│ • EMIフィルタ（Y）  │     │ • コンデンサバンク  │     │ • センサー（GX12）  │
│ • キャニスターリレー│     │ • 8ch MOSFET        │     │ • ポンプ + バルブ   │
└─────────────────────┘     └─────────────────────┘     └─────────────────────┘
```

---

## ⚡ レイヤー1：AC入力・保護（インフラストラクチャ）

電力入力アーキテクチャはシンプルさと最大限の電気的安全性を重視し、重いフィルタリング（EMIフィルターやNTC/突入電流制限など）は、スイッチング電源にすでに組み込まれているプロ用回路に委ねています。

### コンポーネント

| コンポーネント | 機能 |
|---|---|
| **ACガラス管ヒューズ**（3A〜5A） | 必須項目：短絡および火災リスクに対する保護 |
| **SSRリレーモジュール 1CH** | キャニスターフィルター独立制御（ESP32経由、AC） |

### 配線図

<p align="center">
  AC入力：IEC C14インレットからアース、ニュートラル、ライブへ分岐。ライブはヒューズとSSRリレーを経てキャニスターのコンセントへ。
</p>

---

## 🔋 レイヤー2：DCバス・ロジック（分配）

電力をロジックレベルに変換し、重負荷スイッチング時のESP32安定性を維持します。

### コンポーネント

| コンポーネント | 機能 |
|---|---|
| **スイッチング電源 180W** | 12.53Vに調整 |
| **ヒューズ T5AL250V** | 8台のポンプとセンサーの物理的保護 |
| **LM2596** | 5.1Vに調整されたステップダウン（ESP32電源） |
| **1× 470µF 16V** | MOSFETの12V入力に並列（ポンプ起動時の電圧降下を防止） |
| **4× 1000µF 10V** | 5V出力に並列（ESP32のスパイクや変動対策、「無停電電源」として安定動作を保証） |
| **1× 1000µF 10V** | DevKitの3V3ピンとGNDピンに直付け。5Vバンクではこのノードを**カバーできない** — 下記の警告を参照 |

### 配線図

<p align="center">
  DCバス：12.53 V電源がLM2596とMOSFETモジュールに供給し、電力系の戻りはすべてV−端子でスター接続。
</p>

> [!IMPORTANT]
> **電源GND — 電源側でスター接続**：**電源系**の負側基準（MOSFETモジュール、LM2596、ポンプ、ソレノイド）は、グランドループを防ぐため電源のV−端子に直接戻してください。

> [!CAUTION]
> **信号GND — 逆のルール**：**センサー**（フロートスイッチ、超音波）のGNDは、**ESP32のGNDピン**に接続し、電源端子に直接戻しては**いけません**。
>
> ESP32は各入力を*自身の*GNDピンを基準に測定します。電源端子を基準にしたセンサーは、その2点間の電位差をそのままGPIOに与えます。ポンプ起動時にこの差は**−1 V**を超え、ESP32の絶対最小定格−0.3 Vを大きく下回るため、ダメージが蓄積してピンが破損します。
>
> GPIO5とGPIO19はまさにこの原因で焼損しました。[`PROTECAO_ELETRICA.md`](PROTECAO_ELETRICA.md)（ポルトガル語のみ）を参照。

> [!IMPORTANT]
> **3V3のデカップリング — 5Vバンクはこのノードを保護しません。**
>
> 4個の1000 µFはDevKitのAMS1117より**上流**にあります。AMS1117はシリーズレギュレータであり、その制御ループの速度を超えて電荷が通過することはありません。電流ステップに応答するまでの数十マイクロ秒の間、3V3の供給源はボード自身の出力コンデンサだけです — DevKit V1では10〜22 µFです。
>
> ESP32のブラウンアウト検出器は**VDD3P3**を監視します。水槽が停止しポンプも動いていない状態で、5Vバス全体は充電されたまま低下していないにもかかわらず、基板が不規則な間隔で`ESP_RST_BROWNOUT`により再起動していた原因はこれです。この装置で誰の指示もなく動く負荷はWiFiの送信バーストだけです。
>
> **1000 µF 10 V**の電解コンデンサをDevKitの**3V3ピンとGNDピン**に直付けし（リードは短く、負極ストライプをGNDへ）、再起動は止まりました。この事例を説明する原則は、デカップリングは接続されたノードしか助けないということです。超音波センサーが基板側ではなくコネクタ側に専用のコンデンサ対を必要とするのと同じ理由です。

---

## 🌊 レイヤー3：周辺機器・抑制（エッジ）

誘導性ノイズ（フライバック）の軽減および長距離ケーブル（1.2m）でのセンサー読み取り安定化を担当します。

### コンポーネント

| コンポーネント | 用途 | 数量 |
|---|---|---|
| **FR154ダイオード**（高速リカバリ） | 給排水ポンプ | 2 |
| **FR154ダイオード**（高速リカバリ） | ペリスタルティックポンプ（肥料4 + プライム1） | 5 |
| **1N5822ダイオード**（ショットキー） | ソレノイドバルブ（チャンネル8） | 1 |
| **10µF / 22µF 50Vコンデンサ** | ケーブル端でのセンサーデカップリング（GX12） | — |

> [!NOTE]
> **合計：8個のフライバックダイオード** — モーターチャンネルごとに1個（7× FR154 + 1× 1N5822）。すべてケーブル端のモーター近傍に設置。

### 配線図 — アクチュエーター

<p align="center">
  MOSFETチャンネルとバスGNDが1.2 mのケーブルでポンプに届き、フライバックダイオードはモーター側に取り付けられている。
</p>

> [!CAUTION]
> **フライバックダイオード**：必ず**ケーブル端**（モーター近傍）に設置してください。1.2mケーブルがアンテナのようにノイズを放射するのを防ぎます。

### 配線図 — 超音波センサー（A02YYUW、UART）

距離を**UART**で送信する防水超音波センサー。TRIG/ECHOは使わず、分圧回路も不要です。コマンドなしで自動送信し、約100 msごとに1フレームを出力します。

| 線 | 機能 | 接続先 | 備考 |
|---|---|---|---|
| **VCC**（赤） | 電源 | ESP32 3.3V | ⚠️ 5Vは不可 — 下記の警告参照 |
| **GND**（黒） | 帰線 | **ESP32のGNDピン** | ⚠️ 電源端子は不可 |
| **TX** | センサーのデータ出力 | GPIO34（RX2） | 10kΩのプルアップが必要 |
| **RX** | 制御入力 | 3.3V | ファームウェアでは未使用 — 下記の注記参照 |

> データ線2本の色はロットによって異なります。一貫しているのは赤と黒のみです。出力を特定するには、センサーに給電して測定してください。**TX**は約3.3Vで待機し、動きがあります。RXは変化しません。

<p align="center">
  A02YYUW超音波センサーとESP32の配線：VCCは3.3 V、TXは10 kΩプルアップ付きでGPIO34、RXは3.3 V固定、GNDはボードのピン。
</p>

> [!WARNING]
> **3.3Vで給電してください。5Vは不可です。** A02YYUWは3.3〜5Vに対応しますが、出力の論理レベルはVCCに追従します。5VではTX線がGPIO34に5Vを与え、永久的に破損させます。3.3Vで動作させることこそが、分圧回路なしの直結を可能にしています。

> [!IMPORTANT]
> **GPIO34と3.3Vの間に10kΩのプルアップ。** GPIO34は入力専用で、**内部プルアップがありません**。外付け抵抗がないと、ケーブルが外れたりセンサーが無給電の際に線がフローティングとなり、ファームウェアがノイズをデータとして読み取ります。プルアップがあれば線はUARTのアイドル状態であるHighで待機し、データ欠落は `SafetyWatchdog::readUltrasonic()` の2秒タイムアウトで検出される明確な故障になります。

> [!NOTE]
> **制御線（センサーのRX）は未使用です。** ファームウェアは `Serial2` に書き込みを行わず、センサーは自律的に送信します。この線は連続送信モードを維持するため**3.3V**に接続してください。避けるべきはフローティングのまま放置することです。
>
> この線は **GPIO18** に接続します。ファームウェアは `Serial2` に書き込みませんが、ピンはUARTのTXとして宣言したままにしています。これによりラインがHighで保持され、センサーが連続送信モードを維持できます。

> [!TIP]
> **プロトコル：** 9600 baud、8N1。4バイトフレーム — `0xFF`、`DataH`、`DataL`、`Checksum`。距離は**ミリメートル**単位（`(DataH << 8) | DataL`）、チェックサムは `(0xFF + DataH + DataL) & 0xFF` です。ファームウェアはチェックサム不正のフレームを破棄し、5サンプルのメディアンフィルタを適用します。

> [!CAUTION]
> **ローカルデカップリング。** 3.3V動作では定格範囲の下限で動くため、ポンプ起動時の電圧降下に敏感になります。症状は、まさに排水と給水の最中に読み取り値が壊れることです。**100 µF + 100 nFをセンサーのコネクタ側**に取り付けてください（基板側ではありません）。[`PROTECAO_ELETRICA.md`](PROTECAO_ELETRICA.md)（ポルトガル語のみ）を参照。

### 配線図 — 最大水位インターロック（リードスイッチ）

#### なぜリードスイッチが給水ポンプ側にあり、ソレノイド側ではないのか

一見するとソレノイドこそ対象に思えます。水道本管から給水されており、単独なら家中を水浸しにできるからです。しかしソレノイドには**リザーバー内に機械式ボールタップ**がすでに付いています。水位が上がると電子回路を一切介さずに物理的に流路を閉じる弁で、トイレのタンクと同じ仕組みです。

給水ポンプにはそれがなく、付けることもできません。水を水槽の**中へ**押し込む機器であり、吐出側の機械弁ではポンプを止められないからです。止まらなければ水は床に出ます。だからリードスイッチは、何も守るものがなかった側を守っています。

給水系の遮断手段（強い順）:

| アクチュエータ | 物理的遮断 | 電気的遮断 | ファームウェア |
|---|---|---|---|
| ソレノイド（CH8） | **リザーバーの機械式ボールタップ** | — | GPIO19のフロートスイッチ + 8分タイムアウト |
| 給水ポンプ（CH7） | — （不可能） | **ポンプの+12 Vに直列のリードスイッチ** | 超音波センサー + 流量から算出したタイムアウト |

最大水位の遮断は**ファームウェアを経由しません**。給水ポンプの **+12 V** の線に、リードスイッチを直列に挿入します。水が最大水位に達すると接点が開き、ポンプが電源を失って停止します。ESP32がハングしていても、再起動中でも、超音波センサーが沈黙していても、**MOSFETが短絡していても**機能します。

最後の一点が、リードスイッチを信号線ではなく電源線に置く理由です。この種のモジュールのMOSFETはドレイン・ソース間短絡で故障し、その故障ではゲートを切っても何も起こりません。ポンプは回り続け、ファームウェアも信号線上のリードスイッチも止められません。

構成：**NO**（ノーマルオープン）リードスイッチと、水面外のEVAフロートに保持された磁石。通常水位では磁石が近くにあり接点は閉。水位が上がるとフロートが磁石を遠ざけ、接点が開きます。

| 状況 | 磁石 | リード | 12 V | ポンプ |
|---|---|---|---|---|
| 通常水位 | 近い | 閉 | 通過 | 動作可能 |
| 最大水位 | 離れる | 開 | 遮断 | **停止** |
| 断線 | — | — | 遮断 | **停止** |
| MOSFET短絡 | 離れる | 開 | 遮断 | **停止** |

<p align="center">
  給水ポンプの+12 Vに直列に入ったノーマルオープンのリードスイッチと、1 kΩ抵抗と100 nFコンデンサを介してモジュールGNDへ落ちるGPIO33からIN7への信号。
</p>

> [!CAUTION]
> **1 kΩの抵抗は今も必要ですが、理由が変わりました。** リードスイッチが信号線から外れたため、運転中にその線が開くことはありません。しかしESP32の起動時とリセット時にはGPIO33がフローティングになります。MOSFETの入力は蓄積電荷で動作するため、この抵抗がないとフローティングのゲートが電荷を保持し、MOSFETが部分導通したままになる可能性があります。
>
> 製作前に、IN7とモジュールのGND間の抵抗を測定してください。すでに10 kΩ〜100 kΩを示す場合、モジュールに内蔵プルダウンがあり外付け抵抗は不要です。

> [!WARNING]
> **リードスイッチを電源線に入れられるのは、このポンプだからです。** リード接点の定格は0.5〜1 A、10 Wです。本プロジェクトのポンプは12 V、最大5 W、400 mAで、接点にかかるのは4.8 W。余裕は2倍強です。
>
> より大きなポンプに替えると、これは成り立ちません。起動時に数アンペアが流れると接点はアークを起こし、やがて溶着します。インターロックを無効化する、気づけない故障です。その場合はリードスイッチが**リレーのコイル**（数十mA）を駆動し、負荷に見合った定格のリレー接点がポンプを担います。

> [!CAUTION]
> **接点を傷めるのは開く時ではなく閉じる時です。** このポンプはブラシレスで、基板がエポキシで封止されています。つまり入力コンデンサがあります。放電したコンデンサは接点が閉じる瞬間には短絡に見え、そのサージがリードを溶着させます。400 mAを切ること自体は問題ありません。
>
> 実際のリスクは小さいものです。遮断後、ポンプはタイムアウトで停止し、水位が再び下がるのは数時間後の蒸発によるもので、その時にはすべて停止しています。悪いのはポンプ運転中にフロートが水面で揺れ、負荷がかかったまま接点が何十回も断続する場合です。導通テストでは、動作点付近でチャタリングのない**きれいな**遷移であることを確認してください。

> [!TIP]
> **組み立てを封止する前に、解放距離を確認してください。** リードにはヒステリシスがあり、閉じる距離より開く距離のほうが大きくなります。マルチメータの導通モードで磁石を接点が開くまで遠ざけ、その距離を記録します。フロートのストロークはその2〜3倍必要です。また、ストロークの途中のどの位置でも再び閉じないことを確認してください。

> [!IMPORTANT]
> **ファームウェアはリードを見られませんが、その結果は見られます。** 接点から戻る信号線はないため、遮断そのものは不可視です。`_handleRefilling()` が見ているのは**水位の動き**です。ポンプに指令が出ている間、水位は較正済みの速度（`_refillFlowLPM / _litersPerCm`）で上がるはずです。30秒でその35%も動かなければ、ステートマシンは停止し、10分のタイムアウトを待たずに約50秒で `ERROR` に至ります。
>
> 同じ検査は、リードが担わない範囲も覆います。ポンプの故障、ホースの折れ、リザーバー空、そしてこの検査を作る動機となった**超音波センサーの値の固着**です。沈黙したセンサーは `areSensorsConnected()` が既にエラーにしますが、古い値を返し続けるセンサーは「注水が止まった水槽」と区別がつかず、これまではその値に対してポンプがタイムアウトまで回り続けていました。
>
> 以前XKC-Y25静電容量センサー用だった **GPIO4** は、ディスプレイのSDAになりました（このセンサーは一度も設置されず、プロジェクトから削除されました）。現在空いているのは、SDAが移動して空いた **GPIO23** です。2つ目のリードをそこに接続すればファームウェアに可視性が戻りますが、コード変更が必要です。

#### 磁石とリードスイッチの保持：3Dプリントのシーソー

ここまでは回路の話です。それを実行する機構は [`3d_models/reed_level_seesaw.scad`](3d_models/reed_level_seesaw.scad) にあります。

ガラスの縁に載せるシーソーです。内側のアームは発泡スチロールを接着するトレイで終わり、外側のアームは6 × 2 mmの磁石を水平なパッドに**寝かせて**保持します。リードスイッチは5 mmのアクリル管の中にあり、その管が支点の耳から伸びる2本の指を貫きます。回路のどの部分も水に触れません。

| | |
|---|---|
| ガラス | 4.9 mm |
| 磁石のストローク | 23.3 mm |
| リード位置の磁束 — 閉／開 | 約43／約2.4ガウス |
| 縁からの最高点 | 45.5 mm |
| プリント部品 | 4個 |

> [!IMPORTANT]
> **リードスイッチは磁石の真上にありません。これは手抜きではありません。** 寝かせた磁石はその真上に垂直な磁界を出しますが、寝かせたリードスイッチは垂直な磁界を検出できません。その位置では決して閉じません。磁界が水平になるのは磁石の軸から54.7°の線上だけで、だからこそ接点は横方向に9.9 mm、磁石の面から7 mm上に配置されています。この2つの寸法は連動しており（`dy = 1.41 × dz`）、片方だけを動かすとリードがその線から外れます。高さが調整穴ではなく丸穴なのはそのためです。調整するのは管の方で、2本の指の中をスライドさせます。

> [!TIP]
> **解除の余裕を稼ぐのはフロート側ではなく磁石側のアームです。** 磁石のストロークは `2 × arm_out × sin(15°)` であり、開位置での磁界は距離の3乗で減衰します。フロート側のアームを長くすると見た目とは逆の効果になります。それはゲインの分母であり、ストロークをトルクと交換することになるからです。

2本のアームの角度は12歯のフェースカップリングで、30度刻みで選びます。刻みが粗いのは意図的です。動作水位を決めるのはカウンターウェイトであり、その調整幅はフロートの高さとほぼ同じだからです。角度はフロートを水面付近に置ければ十分です。

較正は上のヒントと同じヒステリシス試験に、一段階を加えたものです。レバーを上側のストッパーに当てた状態で接点が閉じるまで管をスライドさせ、そのうえで下側で開くこと、かつ途中のどの位置でも閉じ直さないことを確認します。

プリント：PETGまたはASAで4部品。PLAは吸湿して水辺で変形します。STLは回転済み・z = 0に着座済みで出力され、`reed_seesaw_mesa.stl` は4部品を138 × 86 mmのプレートにまとめています。サポートが必要なのは `bracket` だけで、2か所の開いた空隙です。

### 配線図 — TFT ST7735ディスプレイ (SPI)

1.8インチカラーディスプレイ、128×160ピクセル。**3.3V**で動作 — 5Vは非互換。カスタムピンでソフトウェアSPI（ビットバンギング）を使用します。

| ディスプレイのピン | ESP32接続 | GPIO | 備考 |
|---|---|---|---|
| **VCC** | 3.3V | — | ⚠️ 絶対に5Vを使用しない |
| **GND** | GND | — | |
| **CS** | D15 | GPIO15 | チップセレクト (Chip Select) |
| **RESET** | ENピン | — | ESP32と共有のハードウェアリセット |
| **A0 (DC)** | TX2 | GPIO17 | データ/コマンド (Data/Command) |
| **SDA (MOSI)** | D4 | GPIO4 | SPIデータ |
| **SCK** | RX2 | GPIO16 | SPIクロック |
| **LED** | 3.3V | — | 固定バックライト (空きGPIOなし) |

<p align="center">
  ST7735ディスプレイとESP32の配線：右側ヘッダ下端の連続した6ピンと、ENピンのRESET。
</p>

> [!WARNING]
> ディスプレイの**RESET**ピンはESP32の**EN**ピンに接続してください（GPIOではありません）。これにより、ディスプレイがマイクロコントローラと一緒にリセットされます。ENがHIGH（通常動作）のとき、ディスプレイは正常に動作します。

> [!NOTE]
> ESP32 DevKit V1ブレイクアウトボードでは、**D16**および**D17**はそれぞれ**RX2**および**TX2**とラベル付けされています。端子台のラベルを使用して正しい位置を確認してください。

---

### 配線図 — リザーバーフロートスイッチ

リザーバー満水を検出する水平フロートスイッチ。TPAの `FILLING_RESERVOIR` 状態でソレノイドを閉じます。ファームウェアは信号を受け入れる前に「満水」を5回連続で読み取ることを要求します（デバウンス約250ms）。

| ピン | 接続 | GPIO | 設定 |
|---|---|---|---|
| **端子 1** | GPIO19 | GPIO19 | `INPUT_PULLUP` — LOWでアクティブ |
| **端子 2** | **ESP32のGNDピン** | — | ⚠️ 電源端子には絶対に接続しない |

<p align="center">
  リザーバーのフロートスイッチがGPIO19とESP32のGNDピンの間に接続されている。
</p>

> [!NOTE]
> フロートスイッチは当初GPIO5を使用していましたが、このピンはESP32のストラッピングピンであり干渉が発生していました（静止時約2.5V）。以前はパネルのナビゲーションボタンが使用していたGPIO19に移動しました。

> [!IMPORTANT]
> **パネルのナビゲーションボタンは GPIO5** です（`include/Config.h` の `PIN_BTN`）。フロートスイッチにGPIO19を譲りました。GPIO5はESP32のストラッピングピンのため、電源投入中に押し続けてはいけません。それ以外のタイミングでの一時的な押下は無害です。

---

## 🛠️ 安全な実装上の注意点

1. **AC 接続** — 110V/220Vのすべてのハンダ付け接点および接続部は、最大限の安全性を確保するために熱収縮チューブで絶縁してください。

2. **コンデンサの極性** — すべての電解コンデンサの負極ストライプを確認してください：5.1Vバスの1000µF 10Vと、DevKitの3V3/GNDピン間の1000µF。

3. **フライバックダイオード** — 必ずケーブル端（モーター近傍）に設置し、1.2mケーブルがアンテナのようにノイズを放射するのを防いでください。

4. **スターGND** — すべての負側基準は電源のV−端子に直接戻し、グランドループを防止してください。

5. **サイフォン現象（水力学）** — 排水ポンプ停止後に重力で水槽が排水され続けるのを防ぐため、排水ポンプと並列にソレノイドバルブを配線する（同じMOSFETチャンネルに接続し、それぞれにフライバックダイオードを取り付ける）か、ホースに空気穴を開けてください。

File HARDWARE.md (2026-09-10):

# Documentação de Arquitetura de Hardware: Sistema de Gestão de Aquário

## 📋 Visão Geral

O sistema utiliza uma topologia de **Defesa em Profundidade**, com filtragem de ruído na entrada (AC), estabilização no barramento principal (DC) e supressão de picos indutivos na borda (Atuadores).

```
┌─────────────────────┐     ┌─────────────────────┐     ┌─────────────────────┐
│  CAMADA 1: AC       │ ──► │  CAMADA 2: DC       │ ──► │  CAMADA 3: BORDA    │
│  Entrada/Proteção   │     │  Barramento/Lógica  │     │  Periféricos/Supres.│
│                     │     │                     │     │                     │
│  • Fusível AC       │     │  • Fonte 12.53V     │     │  • Diodos Flyback   │
│  • NTC (Inrush)     │     │  • LM2596 → 5.1V    │     │  • Caps desacopl.   │
│  • Filtro EMI (Y)   │     │  • Banco de Caps    │     │  • Sensores (GX12)  │
│  • Relé Canister    │     │  • MOSFET 8 canais  │     │  • Bombas + Válvula │
└─────────────────────┘     └─────────────────────┘     └─────────────────────┘
```

---

## ⚡ Camada 1: Entrada e Proteção AC (Infraestrutura)

A arquitetura da entrada de energia foca em simplicidade e máxima segurança elétrica, delegando as proteções e filtragens (como Filtro EMI e Termistor NTC/Inrush) para os circuitos profissionais já embutidos na Fonte Colmeia.

### Componentes

| Componente | Função |
|---|---|
| **Fusível de Vidro AC** (3A a 5A) | Item obrigatório: Proteção contra curto-circuito bruto e risco de incêndio |
| **Módulo Relé SSR 1CH** | Controle independente via ESP32 para o filtro Canister (AC) |

### Esquema de Ligação

<p align="center">
  Entrada AC: tomada IEC C14 dividindo terra, neutro e fase; a fase passa por fusível e pelo relé SSR antes da tomada do canister.
</p>

---

## 🔋 Camada 2: Barramento DC e Lógica (Distribuição)

Responsável por converter a potência para os níveis lógicos e manter a estabilidade do ESP32 durante o chaveamento das cargas pesadas.

### Componentes

| Componente | Função |
|---|---|
| **Fonte Colmeia 180W** | Ajustada para 12.53V |
| **Fusível T5AL250V** | Firewall físico para as 8 bombas e sensores |
| **LM2596** | Step-down ajustado para 5.1V (alimentação ESP32) |
| **1× 470µF 16V** | Em paralelo na entrada 12V do MOSFET (Evita queda de tensão quando as bombas ligam) |
| **4× 1000µF 10V** | Em paralelo na saída 5V (Atua como "Nobreak" para o ESP32 aguentar flutuações e picos da rede) |
| **1× 1000µF 10V** | Direto nos pinos 3V3 e GND da devkit. O banco de 5V **não** cobre esse ponto — ver aviso abaixo |

### Esquema de Ligação

<p align="center">
  Barramento DC: fonte de 12,53 V alimentando o LM2596 e o módulo MOSFET, com todos os retornos de potência em estrela no borne V menos.
</p>

> [!IMPORTANT]
> **GND de POTÊNCIA — estrela na fonte**: As referências negativas de **potência** (módulo MOSFET, LM2596, bombas, solenoide) devem retornar diretamente ao borne V− da fonte colmeia, para evitar loops de terra.

> [!CAUTION]
> **GND de SINAL — regra oposta**: O retorno (GND) dos **sensores** — boia e ultrassônico — deve ir para o **pino GND do ESP32**, e **nunca** direto ao borne da fonte.
>
> O ESP32 mede cada entrada em relação ao pino GND *dele*. Um sensor referenciado ao borne da fonte entrega ao GPIO a diferença de potencial entre os dois pontos. Na partida das bombas essa diferença passa de **1 V negativo** — muito além do mínimo absoluto de −0,3 V do ESP32 — e o dano se acumula até o pino abrir.
>
> Foi exatamente assim que os GPIO5 e GPIO19 queimaram. Ver [`PROTECAO_ELETRICA.md`](PROTECAO_ELETRICA.md).

> [!IMPORTANT]
> **Desacoplamento do 3V3 — o banco de 5V não cobre este ponto.**
>
> Os 4× 1000 µF ficam **antes** do AMS1117 da devkit, que é um regulador série. Carga não atravessa esse regulador mais rápido do que a malha de controle dele permite, e nas dezenas de microssegundos que ele leva para responder a um degrau de corrente, a única fonte do 3V3 é o capacitor de saída da própria placa — 10 a 22 µF numa DevKit V1.
>
> O detector de brownout do ESP32 vigia o **VDD3P3**. Foi por isso que a placa reiniciava com `ESP_RST_BROWNOUT` em intervalos irregulares, com o aquário parado e nenhuma bomba ligada, enquanto todo o barramento de 5V seguia carregado e sem afundar. Rajada de transmissão do WiFi é a única carga que se move sem ninguém pedir.
>
> Um eletrolítico de **1000 µF 10 V** soldado direto entre os pinos **3V3 e GND da devkit** — pernas curtas, listra do negativo no GND — encerrou os reinícios. A regra que explica o caso: desacoplamento só ajuda o nó em que está ligado. É a mesma razão pela qual o ultrassônico pede o próprio par de capacitores no conector dele, e não na placa.

---

## 🌊 Camada 3: Periféricos e Supressão (Borda)

Responsável por mitigar o ruído indutivo (Flyback) e estabilizar a leitura dos sensores em cabos longos (1,2m).

### Componentes

| Componente | Aplicação | Qtd |
|---|---|---|
| **Diodos FR154** (Fast Recovery) | Bombas de Recalque e Esgoto | 2 |
| **Diodos FR154** (Fast Recovery) | Bombas Peristálticas (4 Fert + 1 Prime) | 5 |
| **Diodo 1N5822** (Schottky) | Válvula Solenoide (Canal 8) | 1 |
| **Capacitores 10µF / 22µF 50V** | Desacoplamento na ponta dos sensores (GX12) | — |

> [!NOTE]
> **Total: 8 diodos flyback** — um para cada canal com motor (7× FR154 + 1× 1N5822). Todos instalados na ponta do fio, junto ao motor.

### Esquema de Ligação — Atuadores

<p align="center">
  Canal MOSFET e GND do barramento chegando à bomba por fios de 1,2 metro, com o diodo flyback instalado junto ao motor.
</p>

> [!CAUTION]
> **Diodos Flyback**: Devem ser instalados obrigatoriamente **na ponta do fio** (junto ao motor) para evitar que o cabo de 1,2m irradie ruído como uma antena.

### Esquema de Ligação — Sensor Ultrassônico (A02YYUW, UART)

Sensor ultrassônico à prova d'água que envia a distância por **UART**. Não usa TRIG/ECHO e não precisa de divisor de tensão. Transmite sozinho, sem receber comando: um frame a cada ~100 ms.

| Fio | Função | Conexão | Observação |
|---|---|---|---|
| **VCC** (vermelho) | Alimentação | 3.3V do ESP32 | ⚠️ Nunca 5V — ver aviso abaixo |
| **GND** (preto) | Retorno | **Pino GND do ESP32** | ⚠️ Nunca o borne da fonte |
| **TX** | Saída de dados do sensor | GPIO34 (RX2) | Precisa de pull-up de 10kΩ |
| **RX** | Entrada de controle | 3.3V | Não usado pelo firmware — ver nota |

> A cor dos dois fios de dados varia entre lotes; só vermelho e preto são consistentes. Para identificar a saída, alimente o sensor e meça: o **TX** repousa em ~3.3V e apresenta atividade; o RX fica inerte.

<p align="center">
  Sensor ultrassônico A02YYUW ligado ao ESP32: VCC em 3,3 volts, TX no GPIO34 com pull-up de 10 kilo-ohms, RX fixo em 3,3 volts e GND no pino da placa.
</p>

> [!WARNING]
> **Alimente com 3.3V, nunca com 5V.** O A02YYUW aceita 3.3–5V, mas o nível lógico da saída acompanha o VCC. Em 5V a linha de TX entregaria 5V ao GPIO34 e o danificaria permanentemente. É justamente por operar em 3.3V que a ligação dispensa divisor de tensão.

> [!IMPORTANT]
> **Pull-up de 10kΩ entre GPIO34 e 3.3V.** O GPIO34 é input-only e **não possui pull-up interno**. Sem o resistor externo, cabo solto ou sensor sem alimentação deixam a linha flutuando, e o firmware lê ruído como se fosse dado. Com o pull-up a linha repousa em nível alto — que é o repouso do UART — e a ausência de dados vira uma falha limpa, detectada pelo timeout de 2 s em `SafetyWatchdog::readUltrasonic()`.

> [!NOTE]
> **O fio de controle (RX do sensor) não é usado.** Nada no firmware escreve no `Serial2`; o sensor transmite por conta própria. Esse fio deve ir ao **3.3V** para manter o modo de transmissão contínua — o que não se deve fazer é deixá-lo flutuando.
>
> Esse fio fica no **GPIO18**. Nada no firmware escreve no `Serial2`, mas o pino segue declarado como TX do UART justamente para manter a linha em nível alto, que é o que o sensor precisa para permanecer em transmissão contínua.

> [!TIP]
> **Protocolo:** 9600 baud, 8N1. Frame de 4 bytes — `0xFF`, `DataH`, `DataL`, `Checksum`, onde a distância vem em **milímetros** (`(DataH << 8) | DataL`) e o checksum é `(0xFF + DataH + DataL) & 0xFF`. O firmware descarta frames com checksum inválido e aplica filtro de mediana de 5 amostras.

> [!CAUTION]
> **Desacoplamento local.** Alimentado em 3.3V o sensor opera no piso da faixa dele, o que o deixa sensível à queda de tensão quando as bombas partem — o sintoma é leitura corrompida justamente durante o dreno e o recalque. Instale **100 µF + 100 nF no conector do sensor**, não na placa. Ver [`PROTECAO_ELETRICA.md`](PROTECAO_ELETRICA.md).

### Esquema de Ligação — Trava de Nível Máximo (Reed Switch)

#### Por que a trava fica no recalque, e não na solenoide

À primeira vista a solenoide parece o alvo óbvio: ela é alimentada pela rede de água e, sozinha, encheria a casa. Mas ela **já tem uma boia mecânica** no reservatório — uma válvula que fecha o fluxo fisicamente quando a água sobe, sem passar por eletrônica nenhuma. É a mesma ideia da boia de caixa d'água.

A bomba de recalque não tem esse recurso e não pode ter: ela empurra água *para dentro* do aquário, e não existe válvula mecânica que interrompa uma bomba do lado da descarga. Se ela não parar, a água vai ao chão. Por isso o reed protege o canal que não tinha nada.

Resumo das travas de água, do mais forte para o mais fraco:

| Atuador | Trava física | Trava elétrica | Firmware |
|---|---|---|---|
| Solenoide (CH8) | **Boia mecânica no reservatório** | — | Boia elétrica no GPIO19 + timeout de 8 min |
| Bomba de recalque (CH7) | — (impossível) | **Reed em série com o +12 V da bomba** | Ultrassônico + timeout dimensionado pela vazão |

O corte de nível máximo **não passa pelo firmware**. É um reed switch em série com o fio de **+12 V da bomba de recalque**. Se a água atingir o nível máximo, o contato abre, a bomba perde alimentação e para — mesmo com o ESP32 travado, reiniciando, com o ultrassônico mudo **ou com o MOSFET em curto**.

Esse último caso é o motivo de o reed estar na alimentação e não no sinal. MOSFET desses módulos falha em curto entre dreno e fonte, e nessa falha cortar o gate não faz nada: a bomba continua ligada, e nem o firmware nem um reed no sinal conseguem pará-la.

Montagem: reed **NA** (normalmente aberto) com um ímã mantido próximo por uma boia de EVA, fora da água. No nível normal o ímã está presente e o contato fechado. Quando a água sobe, a boia afasta o ímã e o contato abre.

| Situação | Ímã | Reed | 12 V | Bomba |
|---|---|---|---|---|
| Nível normal | presente | fechado | passa | pode funcionar |
| Nível máximo | afastado | aberto | cortado | **parada** |
| Fio rompido | — | — | cortado | **parada** |
| MOSFET em curto | afastado | aberto | cortado | **parada** |

<p align="center">
  Reed switch normalmente aberto em série com o mais 12 volts da bomba de recalque, e o sinal do GPIO33 indo ao IN7 com resistor de 1 kilo-ohm e capacitor de 100 nanofarads para o GND do módulo.
</p>

> [!CAUTION]
> **O resistor de 1 kΩ continua valendo, agora por outro motivo.** Com o reed fora do fio de sinal, a linha nunca fica aberta em operação — mas o GPIO33 flutua durante o boot e o reset do ESP32. A entrada do MOSFET funciona por carga acumulada: sem o resistor, o gate flutuante retém carga e pode manter o MOSFET parcialmente conduzindo.
>
> Antes de montar, meça a resistência entre IN7 e o GND do módulo. Se já houver algo entre 10 kΩ e 100 kΩ, o módulo tem pull-down próprio e o resistor externo é dispensável.

> [!WARNING]
> **O reed só pode ficar na alimentação por causa desta bomba.** Contato de reed é especificado para 0,5–1 A e 10 W. A bomba deste projeto é 12 V, 5 W e 400 mA máximos, o que dá 4,8 W no contato — folga de pouco mais de 2×.
>
> Trocando por uma bomba maior isso deixa de valer. Com vários ampères na partida o contato arca e acaba soldando fechado, falha silenciosa que anula a trava. Nesse caso o reed passa a comandar a **bobina de um relé** (dezenas de mA) e é o contato do relé, dimensionado para a carga, que carrega a bomba.

> [!CAUTION]
> **O que machuca o contato é fechar, não abrir.** A bomba é brushless, com placa vedada em epóxi, ou seja capacitor de entrada. Capacitor descarregado parece curto no instante em que o contato fecha, e é esse pico que solda reed. Abrir 400 mA é tranquilo.
>
> Na prática o risco é pequeno: depois do corte a bomba desliga no timeout, e a água só volta a descer por evaporação, horas depois, com tudo já desligado. O caso ruim é a boia oscilando na lâmina d'água com a bomba ligada, batendo o contato dezenas de vezes sob carga. No teste de continuidade, confirme que a transição é **limpa**, sem repique perto do ponto de disparo.

> [!TIP]
> **Teste a distância de liberação antes de fechar o conjunto.** Reed tem histerese: fecha a uma distância e só abre a uma distância maior. Com o multímetro em continuidade, afaste o ímã até o contato abrir e anote a distância — o curso da boia deve ser 2 a 3 vezes esse valor. Confirme também que ele não volta a fechar em nenhuma posição intermediária do curso.

> [!IMPORTANT]
> **O firmware não enxerga o reed, mas enxerga o efeito dele.** Não há fio de sinal vindo do contato, então o corte em si é invisível. O que o `_handleRefilling()` verifica é o **movimento do nível**: com a bomba comandada, a lâmina tem que subir na taxa calibrada (`_refillFlowLPM / _litersPerCm`). Se em 30 s ela não andar ao menos 35% do esperado, a máquina para e vai a `ERROR` em cerca de 50 s, em vez de queimar os 10 min de timeout.
>
> A mesma verificação cobre o que o reed não é: bomba morta, mangueira dobrada, reservatório vazio e — o caso que motivou a checagem — **leitura congelada do ultrassônico**. Sensor que emudece já dispara erro por `areSensorsConnected()`; sensor que continua respondendo com um número velho é indistinguível de um tanque que parou de encher, e antes disso a bomba rodava até o timeout contra um número parado.
>
> O **GPIO4**, que era do sensor capacitivo XKC-Y25 (nunca instalado, removido do projeto), passou a ser o SDA do display. O pino livre hoje é o **GPIO23**, de onde o SDA saiu — ligar um segundo reed nele devolveria essa visibilidade ao firmware, mas exige mudança de código.

#### Como segurar o ímã e o reed: a gangorra impressa

O trecho acima descreve o circuito. A mecânica que o executa está em [`3d_models/reed_level_seesaw.scad`](3d_models/reed_level_seesaw.scad).

É uma gangorra apoiada na borda do vidro. O braço de dentro termina numa bandeja onde se cola um bloco de isopor; o de fora carrega o ímã de 6 × 2 mm **deitado** numa pá horizontal. O reed vive dentro de um tubo de acrílico de 5 mm que atravessa dois dedos saindo das orelhas do pivô. Nada do circuito toca a água.

| | |
|---|---|
| Vidro | 4,9 mm |
| Curso do ímã | 23,3 mm |
| Campo no reed — fechado / aberto | ~43 / ~2,4 gauss |
| Ponto mais alto acima da borda | 45,5 mm |
| Peças impressas | 4 |

> [!IMPORTANT]
> **O reed não fica em cima do ímã, e isso não é descuido.** Ímã deitado lança campo vertical logo acima de si, e reed deitado não enxerga campo vertical — nessa posição ele nunca fecha. O campo só vira horizontal na linha de 54,7° a partir do eixo do ímã, por isso os contatos ficam 9,9 mm para o lado e 7 mm acima da face dele. As duas cotas são acopladas (`dy = 1,41 × dz`): mexer numa sozinha tira o reed da linha. Por isso a altura é furo redondo, sem ajuste — quem ajusta é o tubo, escorregando dentro dos dois dedos.

> [!TIP]
> **Quem compra margem de desarme é o braço do ímã, não o da boia.** O curso do ímã é `2 × arm_out × sin(15°)`, e o campo no batente de baixo cai com o cubo da distância. Alongar o braço da boia faz o contrário do que parece: ele é o denominador do ganho, então troca curso por torque.

O ângulo entre os dois braços é escolhido num acoplamento dentado de 12 dentes, de 30 em 30 graus. O passo é grosso de propósito: quem define o nível de disparo é o contrapeso, cujo alcance é quase a altura inteira da boia. O ângulo só precisa pôr a boia perto da superfície.

A calibração é o mesmo teste de histerese da dica acima, com uma etapa a mais: escorregue o tubo até o contato fechar com a alavanca no batente de cima, e só então confirme que ele abre no de baixo sem voltar a fechar em nenhum ponto do meio do curso.

Impressão: quatro peças em PETG ou ASA — PLA absorve umidade e deforma perto d'água. As STLs saem já giradas e assentadas em z = 0, e `reed_seesaw_mesa.stl` traz as quatro numa mesa de 138 × 86 mm. Só a peça `bracket` pede suporte, em dois vãos abertos.

### Esquema de Ligação — Display TFT ST7735 (SPI)

Display colorido 1.8" 128×160 pixels. Opera em **3.3V** — incompatível com 5V. Utiliza SPI por software (bit-banging) em pinos customizados.

| Pino do Display | Conexão ESP32 | GPIO | Observação |
|---|---|---|---|
| **VCC** | 3.3V | — | ⚠️ Nunca usar 5V |
| **GND** | GND | — | |
| **CS** | D15 | GPIO15 | Chip Select |
| **RESET** | Pino EN | — | Reset hardware compartilhado com o ESP32 |
| **A0 (DC)** | TX2 | GPIO17 | Data/Command |
| **SDA (MOSI)** | D4 | GPIO4 | Dados SPI |
| **SCK** | RX2 | GPIO16 | Clock SPI |
| **LED** | 3.3V | — | Backlight fixo (sem GPIO livre disponível) |

<p align="center">
  Display ST7735 ligado ao ESP32 com seis pinos seguidos na base do header direito e o RESET no pino EN.
</p>

> [!WARNING]
> O pino **RESET** do display deve ir ao pino **EN** do ESP32 (não a um GPIO). Isso garante que o display é resetado junto com o microcontrolador. Com o pino EN em HIGH (nível normal de operação), o display funciona normalmente.

> [!NOTE]
> No breakout board ESP32 DevKit V1, os pinos **D16** e **D17** aparecem rotulados como **RX2** e **TX2** respectivamente. Use os rótulos do seu terminal para identificar a posição correta.

---

### Esquema de Ligação — Boia do Reservatório

Boia horizontal que indica reservatório cheio. Fecha o solenoide no estado `FILLING_RESERVOIR` do TPA. O firmware exige 5 leituras consecutivas de "cheio" (debounce ~250 ms) antes de aceitar o sinal.

| Pino | Conexão | GPIO | Configuração |
|---|---|---|---|
| **Terminal 1** | GPIO19 | GPIO19 | `INPUT_PULLUP` — ativo em LOW |
| **Terminal 2** | **Pino GND do ESP32** | — | ⚠️ Nunca no borne da fonte |

<p align="center">
  Boia do reservatório entre o GPIO19 e o pino GND do ESP32.
</p>

> [!NOTE]
> A boia usava GPIO5 originalmente, mas aquele pino é um strapping pin do ESP32 e sofria interferência (~2,5 V em repouso). Foi movida para GPIO19, que antes era do botão de navegação do painel.

> [!IMPORTANT]
> **O botão de navegação do painel está no GPIO5** (`PIN_BTN` em `include/Config.h`). Ele perdeu o GPIO19 para a boia. O GPIO5 é strapping pin do ESP32, então não pode ficar pressionado durante a energização; um toque momentâneo em qualquer outro momento é inofensivo.

---

## 🛠️ Notas de Implementação Segura

1. **Conexões AC** — Isole todas as soldas e conexões de 110V/220V com espaguete termo-retrátil para segurança máxima.

2. **Polaridade dos Capacitores** — Verificar a listra negativa em todos os eletrolíticos: os de 1000µF 10V do barramento de 5.1V e o de 1000µF dos pinos 3V3/GND da devkit.

3. **Diodos Flyback** — Devem ser instalados obrigatoriamente na ponta do fio (junto ao motor) para evitar que o cabo de 1,2m irradie ruído como uma antena.

4. **GND Estrela** — Todas as referências negativas devem retornar diretamente ao borne V− da fonte colmeia para evitar loops de terra.

5. **Efeito Sifão (Hidráulica)** — Para evitar o esvaziamento contínuo do aquário por gravidade após o desligamento da bomba de drenagem, ligue uma válvula solenoide em paralelo com a bomba (no mesmo canal MOSFET, garantindo um diodo flyback para cada) ou faça um furo de respiro na mangueira.

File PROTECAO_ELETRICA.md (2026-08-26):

# Proteção Elétrica dos Sensores

Guia em linguagem simples sobre por que a boia do reservatório queimou o pino do ESP32, e o que instalar para não acontecer de novo.

> **Status:** documento de referência. Nada aqui foi implementado ainda.

---

## O problema em uma frase

O ESP32 é delicado: seus pinos aceitam de **0 V a 3,3 V** e nada fora disso. Passar disso, mesmo por um milionésimo de segundo, danifica o pino — e o dano se acumula até ele parar de funcionar de vez.

A boia já matou dois pinos assim: primeiro o GPIO5, depois o GPIO19.

---

## Por que o pino queimou

### Causa 1 — martelo hidráulico, mas elétrico

Você conhece o efeito de fechar uma torneira de golpe: o cano treme e faz barulho. A água estava em movimento e não quer parar.

Eletricidade em bomba e solenoide faz exatamente a mesma coisa. Ao desligar, a corrente não quer parar e gera um pico de **centenas de volts** por um instante. Esse pico "salta" para fios vizinhos, como o cabo da boia — que corre justamente na mesma canaleta dos canos da solenoide e da bomba de recalque.

### Causa 2 — o zero que não é o mesmo zero (a mais provável)

Todo sinal elétrico é medido **em relação a um ponto de referência** — o "zero", o GND.

O ESP32 mede tudo em relação ao **pino GND dele**. Esse é o único zero que ele conhece.

A boia tem 2 fios: um vai no GPIO19, o outro no GND. E hoje esse segundo fio está ligado **direto no borne da fonte** — que é um zero *diferente*, em outro ponto do circuito.

Analogia: duas pessoas medem a altura da água. Uma está no chão firme; a outra, num barco. Quando o barco sobe e desce, a segunda jura que a água mudou de nível — mas foi o **ponto de referência dela** que se moveu.

O borne da fonte é o barco. É para lá que toda a corrente de retorno das bombas desagua. Quando a bomba de recalque parte, ela puxa uma corrente enorme por ali, e aquele ponto "afunda" cerca de **1 volt negativo** em relação ao GND do ESP32.

Aí, quando a boia fecha o contato, ela **liga o GPIO19 direto nesse ponto que afundou**. O pino recebe −1 V. O limite dele é −0,3 V.

Não é ruído vazando pelo ar. É conduzido, por fio, direto no pino. Cada partida de bomba dá mais um golpe, até o pino abrir de vez.

E o pior: **a boia é lida exatamente enquanto a solenoide e a bomba estão ligadas**. O sensor apanha justo na hora em que ele é crítico.

---

## O que já está certo no projeto

Nada disso precisa mudar:

- ✅ **8 diodos flyback**, um por canal com motor (`HARDWARE.md`)
- ✅ Instalados **na ponta do fio, junto ao motor** — que é a posição correta
- ✅ Capacitores de 1000 µF (saída 5 V, alimentando o ESP32) e 470 µF (entrada 12 V do MOSFET) amortecendo a fonte
- ✅ Capacitores de 10 µF / 22 µF previstos para desacoplamento **na ponta dos sensores**, nos conectores GX12 (`BOM.md` item 28)
- ✅ No software: filtro de mediana no ultrassônico e exigência de 5 leituras iguais na boia

> Atenção: esses capacitores seguram **queda de tensão**, que é um problema real e diferente. Eles não fazem nada contra a Causa 2, porque o problema lá não está na linha de energia e sim no caminho de retorno.

---

## O plano, sensor a sensor

Os dois sensores sofrem do mesmo problema de referência de GND, mas a proteção difere: a boia é liga/desliga, e o ultrassônico transmite dados.

| Sensor | GPIO | Tipo | Proteção |
|---|---|---|---|
| **Boia do reservatório** | 19 | Contato seco, 2 fios | Optoacoplador (opcional) |
| **Ultrassônico A02YYUW** | 34 | UART 9600, 4 fios | Desacoplamento + pull-up |

O sensor capacitivo XKC-Y25 que ocupava o GPIO4 **foi removido do projeto** — nunca chegou a ser instalado. A proteção de nível máximo passou a ser um **reed switch em série com o fio de sinal** entre o GPIO33 e a entrada IN7 do módulo MOSFET, que corta a bomba de recalque sem passar pelo firmware. Ver [`HARDWARE.md`](HARDWARE.md).

Mais duas medidas que valem para os dois sensores restantes: o **retorno de GND** e o **roteamento do cabo**.

---

## Passo 1 — o retorno de GND (vale para os dois)

**Não é acrescentar fio.** É mudar **onde o fio de GND encosta**.

Como está hoje:

```
SENSOR ──sinal──────────────► GPIO (ESP32)
       └─GND────────────────► borne V− da FONTE   ← ponto barulhento
```

Como deve ficar:

```
SENSOR ──sinal──────────────► GPIO (ESP32)
       └─GND────────────────► pino GND do ESP32   ← mesma referência
```

Com os dois fios na mesma referência, quando o sensor acionar, o GPIO vai ser ligado exatamente no zero que o ESP32 usa para medir. A diferença passa a ser zero **por construção** — não há como haver desvio, faça a bomba o que fizer.

É trocar um fio de borne. Custo zero, e ataca a raiz. **Faça isso mesmo instalando o optoacoplador**: nos dois casos o lado do ESP32 continua precisando da referência certa.

### Verifique também o GND do módulo MOSFET

Existe um segundo caminho de retorno que costuma passar despercebido, e ele encaixa ainda melhor com o histórico de GPIO queimado.

Os 8 canais chaveiam pelo **lado baixo**, então a corrente de retorno de *todas* as bombas passa por um único parafuso: o terminal GND do módulo. Se esse borne afrouxar ou oxidar, vários ampères vão procurar outro caminho de volta ao negativo da fonte — e o único disponível são os oito fios de sinal de 22 AWG, entrando direto nos GPIOs.

Isso explica o padrão melhor do que ruído irradiado: é **conduzido**, é da ordem de ampères, e acontece exatamente no instante em que uma bomba parte.

**A boa notícia:** o módulo em uso tem entradas **optoacopladas**. Se a barreira galvânica estiver íntegra, essa corrente simplesmente não tem caminho até o ESP32. Mas placas baratas frequentemente unem os dois GNDs por um jumper de solda ou uma trilha, e aí a barreira é decorativa.

Meça com o ohmímetro, módulo totalmente desconectado, entre o **GND do lado de controle** e o **GND do lado de potência**:

- **Aberto** — isolamento real. Mantenha assim: **não una esses dois GNDs em lugar nenhum**. Isso é mais valioso do que qualquer outra proteção nesta lista.
- **~0 Ω** — GNDs compartilhados. Procure o jumper de solda; cortá-lo devolve a proteção de verdade.

Independente do resultado, **reaperte o borne de GND do módulo** e todos os bornes de potência depois da primeira hora de operação. Foi um parafuso solto que causou o falso alarme diagnosticado neste projeto.

---

## Passo 2 — optoacoplador na boia (opcional)

Um optoacoplador transmite o sinal **por luz**, não por eletricidade. Dentro dele há um LED de um lado e um sensor de luz do outro, sem contato elétrico entre as partes.

Analogia: em vez de gritar através de uma parede, você pisca uma lanterna. A mensagem passa; o barulho não.

**O efeito:** o cabo comprido que vai até o sensor **deixa de tocar o ESP32**. Qualquer pico que ele capte descarrega no circuito de 12 V — que é robusto e aguenta — em vez de entrar num pino de 3,3 V.

Bônus: o sinal passa a viajar em 12 V no cabo. Um ruído de 2 V é fatal para 3,3 V e irrelevante para 12 V.

**O lado do ESP32:**

```
   3,3V ──[ 10 kΩ ]──┬────────── GPIO (4 ou 19)
                     │
            coletor ─┘
            emissor ──────────── GND do ESP32
                  PC817
```

---

### Sensor 1 — Boia do reservatório (GPIO19)

Contato seco, 2 fios. É só uma chave: fecha quando o reservatório enche.

```
   +12V ───[ BOIA ]───[ 1,5 kΩ ]───┬────►|────┬─── GND (12V)
                                   │  LED     │
                                   └────|◄────┘
                                     1N4148
```

O 1N4148 fica **em antiparalelo com o LED** (catodo do LED ligado ao anodo do diodo). Serve para proteger o LED de tensão reversa vinda do cabo.

Corrente no LED: 12 V ÷ 1,5 kΩ ≈ **8 mA**. Folgado para o PC817, que trabalha bem entre 5 e 20 mA.

---

### Sensor 2 — Ultrassônico A02YYUW (GPIO34)

**Este não leva optoacoplador**, e vale explicar por quê.

O PC817 é ótimo para liga/desliga, mas lento demais para transmitir **dados**. O A02YYUW fala UART a 9600 baud, e o PC817 deformaria os bits. Existem optoacopladores rápidos que dariam conta, mas como o sensor é ativo e precisa de alimentação descendo pelo mesmo cabo, isolar só a linha de dados resolveria metade do problema — complicação sem retorno proporcional.

E o problema dele é outro: **ele não queima, ele mente.**

Alimentado em 3,3 V, o A02YYUW opera no piso da faixa dele. Quando a bomba parte e a tensão cai por um instante, o sensor reinicia e devolve leitura corrompida — justamente durante o dreno e o recalque, quando o nível precisa estar correto.

| Proteção | Para quê |
|---|---|
| **Capacitor 100 µF + 100 nF no conector do sensor** | Reserva local de energia; segura a queda de tensão. É a mais importante |
| **Resistor de 10 kΩ do GPIO34 para 3,3 V** | O GPIO34 não tem resistor interno. Sem ele, cabo solto = leitura de lixo. Com ele, cabo solto = silêncio limpo, que o timeout de 2 s do firmware já trata |
| **Resistores de 470 Ω nas linhas de dados** | Limita corrente em caso de falha |
| **Filtro de ferrite no cabo** | Bloqueia ruído captado ao longo do caminho |

> ⚠️ **Nunca alimente o A02YYUW com 5 V.** O nível lógico da saída dele acompanha a alimentação, e 5 V no GPIO34 destrói o pino. Se for usar um regulador dedicado, tem que ser de **3,3 V**.

---

## A lógica do firmware não muda

Vale conferir, porque é o que garante que nada precisa ser reprogramado:

| Sensor | Evento | LED do opto | GPIO | O que o firmware espera |
|---|---|---|---|---|
| Boia | reservatório cheio | acende | LOW | `isReservoirFull()` → `== LOW` ✅ |

Bate com o código atual. **Nenhuma linha muda.**

---

## O que acontece se um cabo romper

| Sensor | Cabo rompido | Consequência |
|---|---|---|
| **Boia** | GPIO fica alto → "reservatório nunca enche" | O enchimento estoura o tempo limite e o TPA para com erro. **Falha segura** |
| **Ultrassônico** | sem dado → `_sensorsConnected` vira falso após 2 s | As verificações por sensor são puladas. O recalque passa a depender só do tempo limite |
| **Reed da trava** | contato aberto = mesmo efeito de nível máximo | A bomba de recalque não liga. **Falha segura** |

O reed merece destaque: por ser NA com o ímã presente no repouso, fio rompido, conector solto e ímã caído levam todos ao mesmo resultado — bomba desligada. A trava falhando também para a bomba.

O caso que sobra é **mecânico**: se a boia de EVA emperrar e não afastar o ímã, o contato fica fechado e a trava não age. É o único caminho que ainda leva a transbordo, e nenhum componente elétrico cobre isso — só folga generosa na guia e o teste da distância de liberação.

## Proteção na fonte do ruído — TVS nos canais das bombas

Aqui está a metade que falta da proteção contra o martelo elétrico.

O diodo flyback fica junto ao motor e protege muito bem *aquele lado*. Mas o cabo de 1,2 m entre a placa e o motor também guarda energia, e essa parte o diodo não alcança — ela descarrega **do lado da placa**.

Um **TVS** é um componente que fica inerte até a tensão passar do limite, e então "curto-circuita" o excesso para o GND. Como um ladrão de pressão.

**Onde:** um em cada canal de bomba de dreno, bomba de recalque e solenoide.

---

## Roteamento, cabo e vedação — custo zero

- Afastar os cabos de sensor pelo menos **15 cm** dos cabos de força. Se precisar cruzar, cruzar em ângulo de 90°.
- **Drip loop**: deixar uma barriga para baixo no cabo antes do conector, para a água escorrer e pingar no chão em vez de correr para dentro do plugue.
- Vedar os conectores com termo-retrátil com cola.
- **Filtro de ferrite** no cabo, junto do ESP32. Ajuda independente do tipo de cabo e não exige nada dele.

**Sobre o cabo — não precisa ser par trançado.**

Um cabo com 2 condutores dentro da mesma capa já entrega quase todo o benefício, porque o que importa é os dois fios percorrerem o mesmo caminho, colados. A torção acrescenta pouco além disso. Não vale trocar de cabo por causa disso.

**Sobre a haste metálica de enrijecimento**, se o cabo tiver uma:

Solta, sem ligação em ponta nenhuma, ela é uma antena deitada ao lado dos fios de sinal. Duas opções:

- **Ligue ao pino GND do ESP32, só nessa ponta.** A outra ponta fica solta, sem encostar em nada. Assim a haste vira blindagem e passa a trabalhar a favor.
- **Se a haste tiver qualquer contato com a água do reservatório, não ligue** — corrente de fuga na água causa eletrólise. Nesse caso deixe solta mesmo.

Ligar nas **duas** pontas é o pior dos mundos: cria loop de terra e piora. Uma ponta só.

---

## Antes de comprar: faça este teste

Confirma a Causa 2 em dois minutos, com multímetro comum.

1. Multímetro em **tensão contínua (DC)**, escala de 2 V ou menor
2. Ponta preta no **pino GND do ESP32**
3. Ponta vermelha no **barramento de terra** onde as bombas retornam
4. Ligue e desligue a bomba de recalque algumas vezes

**Leitura acima de 0,2 V confirma o diagnóstico.** E o pico real é bem maior do que isso — o multímetro é lento demais para mostrar, ele só enxerga a média.

### Teste extra: o GPIO19 morreu mesmo?

Com a boia desconectada, meça o GPIO19 contra o GND.

- **~3,3 V** → o pino está vivo; o problema foi no cabo ou no conector
- **Perto de 0 V ou instável** → o pino se foi

---

## Lista de compras

Tudo são componentes comuns e baratos de loja de eletrônica.

**Para a trava de nível máximo:**

| Item | Quantidade | Para quê |
|---|---|---|
| Reed switch NA + ímã | 1 | Corte por hardware da bomba de recalque |
| Resistor 1 kΩ | 1 | Pull-down do IN7, **lado do módulo** |
| Capacitor 100 nF | 1 | Filtro na entrada do IN7 |

**Para o optoacoplador da boia** (opcional):

| Item | Quantidade | Para quê |
|---|---|---|
| Optoacoplador PC817 | 1 | Isolar a boia |
| Resistor 1,5 kΩ | 1 | Limitar corrente do LED |
| Resistor 10 kΩ | 1 | Pull-up da saída do opto |
| Diodo 1N4148 | 1 | Proteger o LED de tensão reversa |

**Para o ultrassônico:**

| Item | Quantidade | Para quê |
|---|---|---|
| Capacitor 100 µF | 1 | Reserva de energia no conector do sensor |
| Capacitor 100 nF | 1 | Em paralelo com o de 100 µF, para ruído rápido |
| Resistor 10 kΩ | 1 | Pull-up do GPIO34 |
| Resistor 470 Ω | 2 | Linhas de dados |

**Comum:**

| Item | Quantidade | Para quê |
|---|---|---|
| TVS SMAJ18A ou P6KE18A | 3 | Canais de dreno, recalque e solenoide |
| Filtro de ferrite clip-on | 3 | Um por cabo de sensor |

---

## Perguntas rápidas

**Existe um pino mais resistente no ESP32?**
Não. Todos têm a mesma fragilidade e o mesmo limite. Trocar de pino não resolve — a prova é que já saímos do 5 para o 19 e o 19 morreu igual.

**Então preciso mudar a boia de pino?**
Não. Com o optoacoplador instalado, o GPIO19 volta a servir perfeitamente, sem mudar uma linha de código.

**Por que o ultrassônico não leva optoacoplador?**
Porque ele transmite dados, não liga/desliga. O PC817 é lento demais para 9600 baud e deformaria os bits. E o problema dele é outro: ele não queima, ele devolve leitura errada quando a tensão cai. A proteção dele é o capacitor no conector.

**E a proteção contra transbordo?**
É o reed switch, em série com o fio de sinal entre o GPIO33 e o IN7 do módulo MOSFET. Ele corta a bomba de recalque **sem passar pelo firmware**, então funciona com o ESP32 travado ou com o ultrassônico devolvendo leitura errada. É mais forte que qualquer verificação em código, e por isso o sensor capacitivo foi removido do projeto.

**E se o GPIO19 estiver realmente morto?**
O **GPIO35** é a melhor opção livre. Precisa de um resistor de 10 kΩ para 3,3 V, porque ele não tem resistor interno. Evite o GPIO5 e o GPIO0 — são pinos especiais usados na inicialização do chip.

**Dá para nunca mais queimar o ESP32?**
A estratégia mais segura é tirar os sensores do ESP32 e ligá-los num **expansor PCF8574** — um chip pequeno, em soquete, que conversa com o ESP32 por dois fios curtos dentro da caixa. Se queimar, você troca uma peça de poucos reais em vez da placa inteira.

---

## Ordem de execução

1. **Fazer o teste do multímetro** — confirma o diagnóstico antes de gastar
2. **Mover o retorno de GND dos sensores** para o pino GND do ESP32 (custo zero)
3. **Reed switch** na linha GPIO33→IN7, com o resistor de 1 kΩ do lado do módulo
4. **Capacitor no conector do ultrassônico** — resolve leitura errada durante as bombas
5. **Optoacoplador na boia** (GPIO19) — opcional, se o ajuste de GND não bastar
6. **TVS nos três canais** de bomba e solenoide
7. **Roteamento e vedação** dos cabos

Os passos 2 e 3 cobrem o essencial: o primeiro protege o pino, o segundo protege o aquário. O resto é margem.

> Nada disso exige mudança no firmware. A lógica dos sensores continua ativa em LOW nos dois casos.

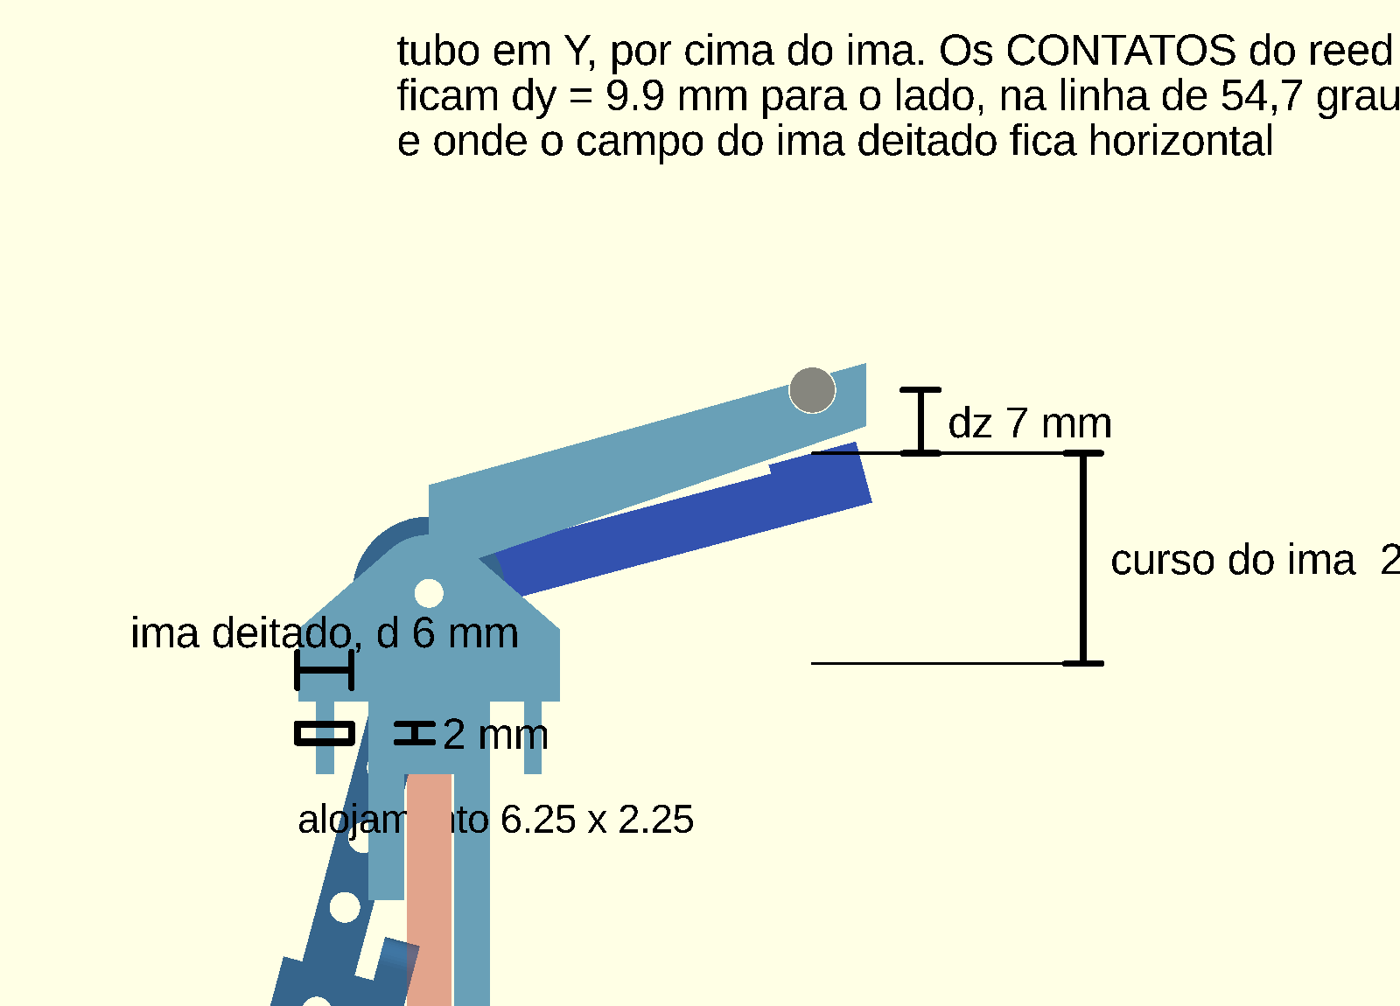
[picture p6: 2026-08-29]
3d_models/reed_seesaw_cotas_reed.png

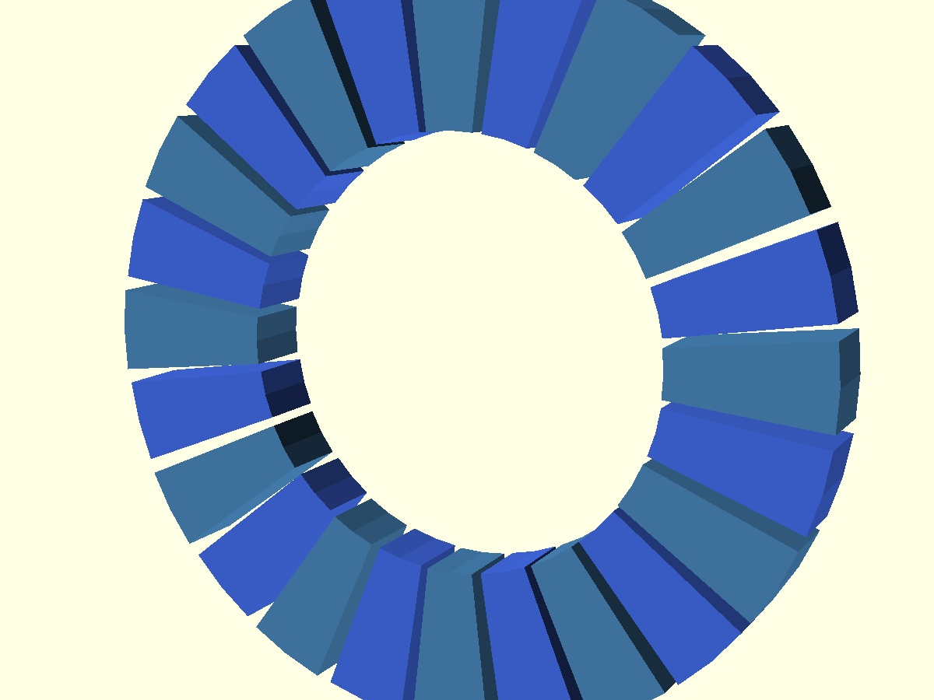
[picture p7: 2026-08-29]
3d_models/reed_seesaw_dentes_encaixe.png

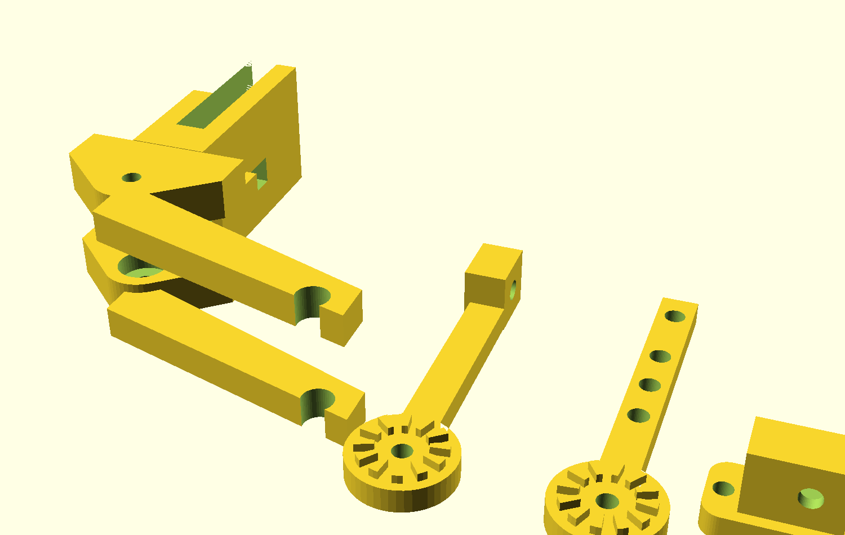
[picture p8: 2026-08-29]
3d_models/reed_seesaw_mesa.png

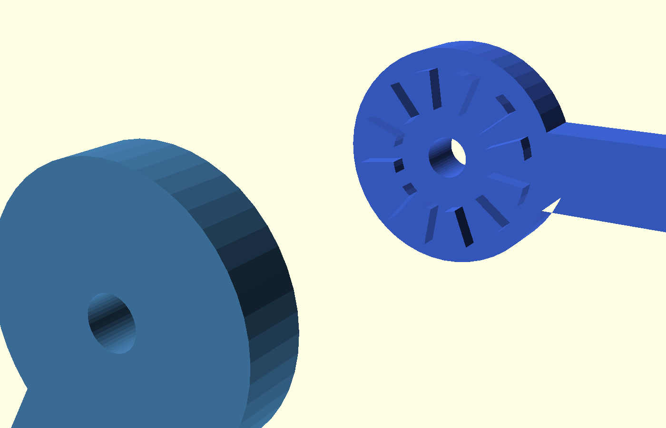
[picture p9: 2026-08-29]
3d_models/reed_seesaw_dentes.png

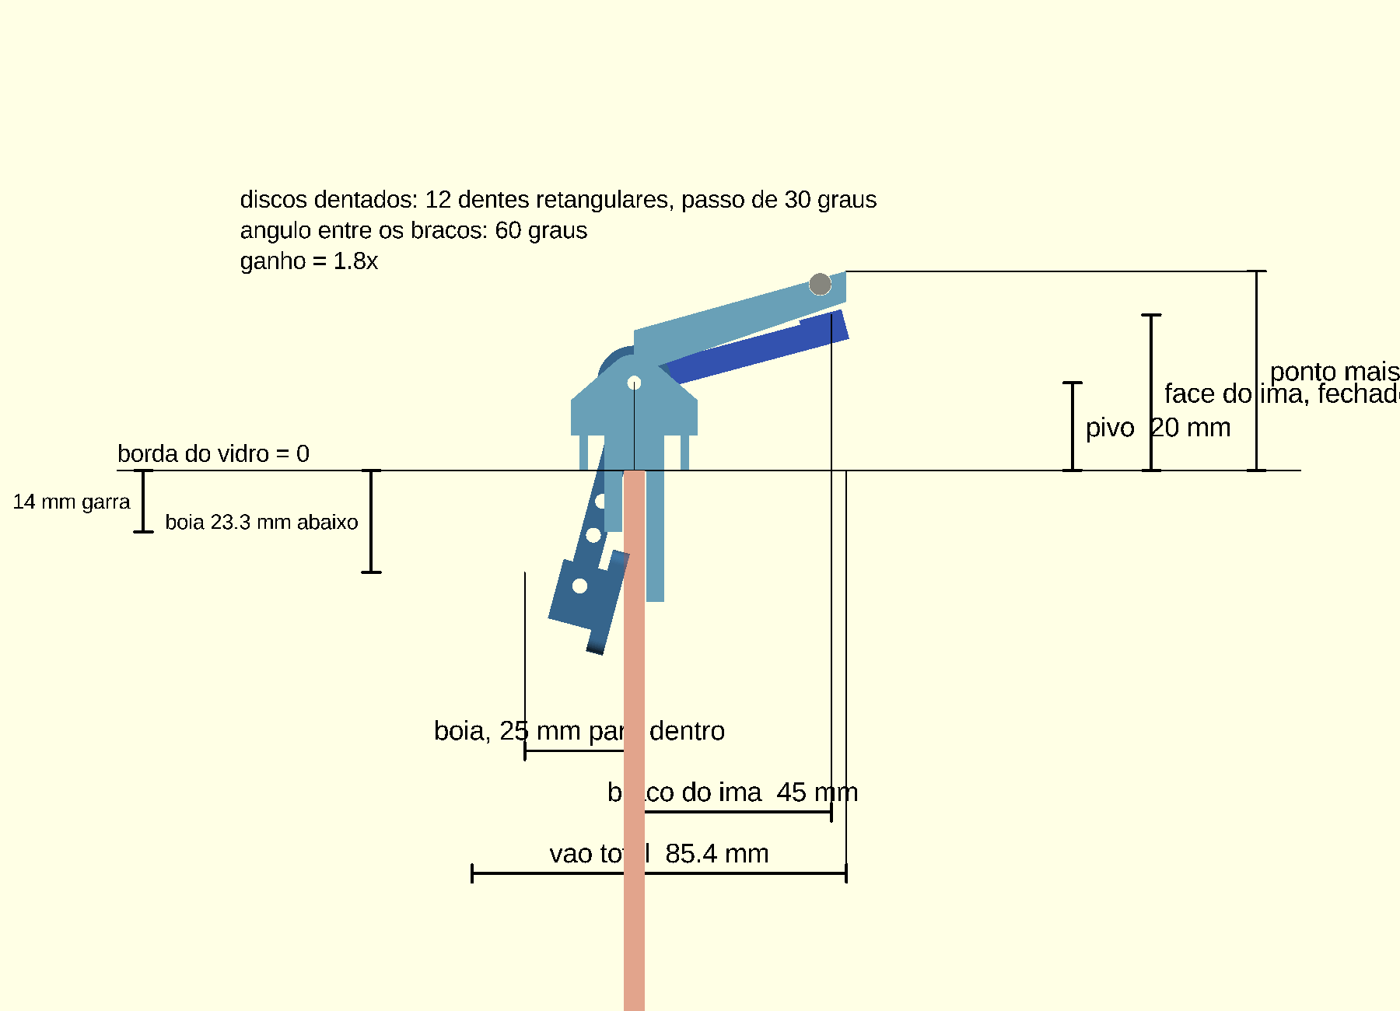
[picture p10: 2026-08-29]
3d_models/reed_seesaw_cotas.png

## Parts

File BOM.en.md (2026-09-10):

# BOM — Bill of Materials

Complete component list for the IARA system.

---

## 🧠 Controller

| # | Component | Specification | Qty |
|---|---|---|---|
| 1 | ESP32 DevKit V1 | 38 pins, WROOM-32 | 1 |

---

## ⚡ Layer 1 — AC Input & Protection

| # | Component | Specification | Qty |
|---|---|---|---|
| 2 | IEC C14 Connector | Male panel-mount with fuse | 1 |
| 3 | AC Fuse | 3A–5A, 250V | 1 |
| 4 | NTC 5D-11 | Inrush current limiter, 5Ω cold | 1 |
| 5 | NDF 222M Capacitor | Y capacitor, Phase–Ground | 1 |
| 6 | NDF 222M Capacitor | Y capacitor, Neutral–Ground | 1 |
| 7 | SSR Relay Module 1CH | SSR, Canister filter control (AC) | 1 |

---

## 🔋 Layer 2 — DC Bus & Logic

| # | Component | Specification | Qty |
|---|---|---|---|
| 8 | 180W Switching PSU | 12V (adjusted to 12.53V) | 1 |
| 9 | T5AL250V Fuse | 5A, DC protection | 1 |
| 10 | LM2596 Module | Adjustable step-down (→ 5.1V) | 1 |
| 11 | 8-Channel MOSFET Module | Optocoupled inputs, **3.3 V version**, PWM on every channel, 12V. MOSFET part not identified — see the note below | 1 |
| 12 | 470µF Electrolytic Cap | 16V, MOSFET input filter | 1 |
| 13 | 1000µF Electrolytic Cap | 10V — 4 on the 5V bus, 1 straight across the devkit's 3V3/GND pins (see `HARDWARE.md`) | 5 |

---

## 🌊 Layer 3 — Actuators

| # | Component | Specification | Qty |
|---|---|---|---|
| 14 | 12V Peristaltic Pump | Fertilizers (CH1–CH4) | 4 |
| 15 | 12V Peristaltic Pump | Prime / dechlorinator (CH5) | 1 |
| 16 | 12V Submersible Pump | Drain / sewage (CH6) | 1 |
| 17 | 12V Submersible Pump | Refill / top-up (CH7) | 1 |
| 18 | 12V Solenoid Valve | Normally closed (CH8) | 1 |
| 18b| Mechanical float valve | Physically shuts the reservoir inlet — independent of any electronics | 1 |
| 19 | Canister Filter | Controlled via AC relay | 1 |

---

## 📡 Sensors

| # | Component | Specification | Qty |
|---|---|---|---|
| 20 | A02YYUW | Waterproof ultrasonic, UART, **3.3V** | 1 |
| 21 | Reed switch + magnet | Max-level interlock, NO, in series GPIO33→IN7 | 1 |
| 22 | Float Switch | Reservoir level (GPIO 19) | 1 |
| 23 | DS3231 | RTC module I2C (SDA 21 / SCL 22) | 1 |
| 24 | 1.8" TFT Display | ST7735, SPI, 128×160 | 1 |
| 24b| Push/Tactile Button | Display navigation (GPIO 0) | 1 |

---

## 🛡️ Protection & Filtering

| # | Component | Specification | Qty |
|---|---|---|---|
| 25 | FR154 Diode | Fast Recovery, pump flyback | 7 |
| 26 | 1N5822 Diode | Schottky, solenoid flyback | 1 |
| 27 | 10kΩ Resistor | ¼W, GPIO34 pull-up (A02YYUW TX) | 1 |
| 28 | 10µF / 22µF Capacitor | 50V, sensor decoupling | 2–4 |

---

## 🔌 Connectors & Accessories

| # | Component | Specification | Qty |
|---|---|---|---|
| 29 | GX12 Aviation Connector | Panel mount, for remote sensors | 2–4 |
| 30 | Shielded Multi-core Cable | 4-5 cores, solderable to GX12, 1.2m | 2–4 |
| 31 | KRE / Wago Terminal | Power connections | ~20 |
| 32 | Heat-Shrink Tubing | NTC and solder insulation | 1m |
| 33 | 22 AWG Wire | Signal / sensors | ~5m |
| 34 | 18 AWG Wire | Power / pumps | ~10m |

---

## 📝 Notes on the MOSFET module

The module in use is an **8-channel board with optocoupled inputs, 3.3 V version**, with PWM on every channel. Listing: AliExpress item `1005010404945969`.

**The MOSFET part number is not confirmed.** The BOM said `IRF540N or equivalent`, which was a guess — and a poor one: the IRF540N's V<sub>GS(th)</sub> is 2.0–4.0 V and its R<sub>DS(on)</sub> is specified at V<sub>GS</sub> = 10 V. A real IRF540N on a 3.3 V gate would sit in the linear region, dissipating watts in a TO-220 with no heatsink inside a sealed box. The module works, so it is probably **not** an IRF540N. Read the marking off the package and record it here — whoever replaces a blown channel will buy whatever this file says.

### Why this module needs no input pull-downs

On a direct-drive board the IN terminal goes to the MOSFET **gate**. A gate is capacitive and has no current threshold: stray voltage accumulates charge and the transistor starts conducting. That is why such boards need a 10 kΩ pull-down on every input — without one, ESP32 GPIO13 and GPIO14, which come out of reset with ~45 kΩ internal pull-ups, could run pumps during the ~300 ms bootloader window, on every reset and every flash.

Here the IN terminal drives an **LED** inside the optocoupler, and an LED is a threshold device — it needs 5 to 20 mA to light. The internal pull-up can supply at most `(3.3 − 1.2) / 45k ≈ 47 µA`, two to three orders of magnitude short. **The optocoupler already does the pull-down's job.**

Confirm with a multimeter in **diode mode** between IN and the control-side GND: ~1.0–1.3 V one way and open the other means it is an LED. If it reads a resistance both ways, the board is direct-drive and the pull-downs become mandatory again.

### Check whether the isolation is real

Cheap boards advertised as optocoupled often bridge the two grounds with a solder jumper or a trace, which makes the barrier cosmetic.

That matters a great deal here. All eight channels switch low-side, so every pump's return current flows through the module's GND terminal. If that screw goes high-resistance, several amps look for another path back to the supply negative — and the only one available is the signal wires, straight into the GPIOs. It is the explanation that best fits the burned GPIO5 and GPIO19: conducted, amps, and happening exactly when a pump starts.

**With the galvanic barrier intact that current has no path to the ESP32.** Measure with an ohmmeter, module disconnected, between the control-side GND and the load-side GND:

- **Open** — real isolation. Keep it that way: do not bond those two grounds anywhere.
- **~0 Ω** — shared grounds. Look for the solder jumper; cutting it restores the protection.

### PWM through an optocoupler

`FertManager` runs LEDC at 5 kHz on channels 1 to 5. A common optocoupler (PC817 and similar) turns off considerably more slowly than it turns on, so the duty reaching the gate is not exactly the one commanded, especially at low values. Flow calibration absorbs this because it is measured empirically — but if a channel will not turn at low PWM, that is the reason, not a weak pump.

---

## 📊 Component Summary

| Category | Items |
|---|---|
| Electrolytic Capacitors | 6–10 |
| Diodes (flyback) | 8 |
| Resistors | 1 |
| Motors / Pumps | 7 |
| Sensors | 4 |
| Modules (ESP32, LM2596, MOSFET, Relay, RTC, TFT) | 6 |

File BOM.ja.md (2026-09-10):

# BOM — 部品表

IARAシステムの全コンポーネントリスト。

---

## 🧠 コントローラー

| # | コンポーネント | 仕様 | 数量 |
|---|---|---|---|
| 1 | ESP32 DevKit V1 | 38ピン、WROOM-32 | 1 |

---

## ⚡ レイヤー1 — AC入力・保護

| # | コンポーネント | 仕様 | 数量 |
|---|---|---|---|
| 2 | IEC C14コネクタ | パネルマウント（ヒューズ付） | 1 |
| 3 | ACヒューズ | 3A–5A、250V | 1 |
| 4 | NTC 5D-11 | 突入電流制限器、5Ω（冷時） | 1 |
| 5 | NDF 222Mコンデンサ | Yコンデンサ、相–接地 | 1 |
| 6 | NDF 222Mコンデンサ | Yコンデンサ、中性–接地 | 1 |
| 7 | SSRリレーモジュール 1CH | SSR、キャニスターフィルター制御（AC） | 1 |

---

## 🔋 レイヤー2 — DCバス・ロジック

| # | コンポーネント | 仕様 | 数量 |
|---|---|---|---|
| 8 | スイッチング電源 180W | 12V（12.53Vに調整） | 1 |
| 9 | ヒューズ T5AL250V | 5A、DC保護 | 1 |
| 10 | LM2596モジュール | 可変ステップダウン（→ 5.1V） | 1 |
| 11 | 8チャンネルMOSFETモジュール | フォトカプラ絶縁入力、**3.3Vバージョン**、全チャンネルPWM対応、12V。MOSFETの型番は未確認 — 下記の注記を参照 | 1 |
| 12 | 電解コンデンサ 470µF | 16V、MOSFET入力フィルタ | 1 |
| 13 | 電解コンデンサ 1000µF | 10V — 4個は5Vバス、1個はDevKitの3V3/GNDピンに直付け（`HARDWARE.md`を参照） | 5 |

---

## 🌊 レイヤー3 — アクチュエーター

| # | コンポーネント | 仕様 | 数量 |
|---|---|---|---|
| 14 | 12Vペリスタルティックポンプ | 肥料（CH1–CH4） | 4 |
| 15 | 12Vペリスタルティックポンプ | プライム/脱塩素剤（CH5） | 1 |
| 16 | 12V水中ポンプ | 排水用（CH6） | 1 |
| 17 | 12V水中ポンプ | 給水用（CH7） | 1 |
| 18 | 12Vソレノイドバルブ | 常閉型（CH8） | 1 |
| 18b| 機械式ボールタップ | リザーバーの給水口を物理的に閉じる（電子回路に依存しない） | 1 |
| 19 | キャニスターフィルター | ACリレー制御 | 1 |

---

## 📡 センサー

| # | コンポーネント | 仕様 | 数量 |
|---|---|---|---|
| 20 | A02YYUW | 防水超音波センサー、UART、**3.3V** | 1 |
| 21 | リードスイッチ + 磁石 | 最大水位インターロック、NO、GPIO33→IN7に直列 | 1 |
| 22 | フロートスイッチ | リザーバー水位（GPIO 19） | 1 |
| 23 | DS3231 | RTCモジュール I2C（SDA 21 / SCL 22） | 1 |
| 24 | TFTディスプレイ 1.8" | ST7735、SPI、128×160 | 1 |
| 24b| プッシュ/タクタイルボタン | ディスプレイナビゲーション (GPIO 0) | 1 |

---

## 🛡️ 保護・フィルタリング

| # | コンポーネント | 仕様 | 数量 |
|---|---|---|---|
| 25 | FR154ダイオード | 高速リカバリ、ポンプフライバック | 7 |
| 26 | 1N5822ダイオード | ショットキー、ソレノイドフライバック | 1 |
| 27 | 10kΩ抵抗 | ¼W、GPIO34のプルアップ（A02YYUWのTX） | 1 |
| 28 | 10µF / 22µFコンデンサ | 50V、センサーデカップリング | 2–4 |

---

## 🔌 コネクタ・アクセサリ

| # | コンポーネント | 仕様 | 数量 |
|---|---|---|---|
| 29 | GX12航空コネクタ | パネルマウント、リモートセンサー用 | 2–4 |
| 30 | シールド付き多芯ケーブル | 4〜5コア、GX12用はんだ付け可、1.2m | 2–4 |
| 31 | KRE / Wagoターミナル | 電力接続 | 約20 |
| 32 | 熱収縮チューブ | NTCおよびハンダの絶縁 | 1m |
| 33 | 22 AWGワイヤ | 信号/センサー | 約5m |
| 34 | 18 AWGワイヤ | 電力/ポンプ | 約10m |

---

## 📝 MOSFETモジュールに関する注記

使用しているモジュールは**フォトカプラ絶縁入力の8チャンネル基板、3.3Vバージョン**で、全チャンネルPWM対応です。出品: AliExpress 商品番号 `1005010404945969`。

**MOSFETの型番は未確認です。** BOMには `IRF540N相当` と書かれていましたが、これは推測であり、しかも筋の悪い推測でした。IRF540NのV<sub>GS(th)</sub>は2.0〜4.0 Vで、R<sub>DS(on)</sub>はV<sub>GS</sub> = 10 Vでの規定値です。3.3Vのゲートで本当にIRF540Nを使えば線形領域で動作し、放熱器なしのTO-220が密閉ケース内で数ワットを消費します。モジュールは正常に動作しているので、**IRF540Nではない**可能性が高いです。パッケージの刻印を読み取り、ここに記録してください。焼損したチャンネルを交換する人は、このファイルに書かれている部品を購入します。

### このモジュールに入力プルダウンが不要な理由

直接駆動基板では、IN端子はMOSFETの**ゲート**に接続されます。ゲートは容量性で電流しきい値を持たないため、迷走電圧が電荷として蓄積し、トランジスタが導通し始めます。そのため、そうした基板では各入力に10 kΩのプルダウンが必要です。これがないと、リセット直後に約45 kΩの内部プルアップを持つESP32のGPIO13とGPIO14が、ブートローダーの約300 msの間、リセットのたび、書き込みのたびにポンプを動かしかねません。

本モジュールではIN端子がフォトカプラ内部の**LED**を駆動します。LEDはしきい値素子であり、点灯には5〜20 mAを要します。内部プルアップが供給できるのは最大でも `(3.3 − 1.2) / 45k ≈ 47 µA` で、2〜3桁不足しています。**フォトカプラがプルダウンの役割をすでに果たしています。**

テスターの**ダイオードモード**で、INと制御側GNDの間を確認してください。片方向で約1.0〜1.3 V、逆方向で開放ならLEDです。両方向とも抵抗値を示す場合は直接駆動基板であり、プルダウンが再び必須になります。

### 絶縁が本物かどうかを確認する

「フォトカプラ付き」と謳う安価な基板は、はんだジャンパやパターンで両側のGNDを繋いでいることが多く、その場合、絶縁は名ばかりです。

本プロジェクトではこれが非常に重要です。8チャンネルすべてがローサイドスイッチングなので、全ポンプの帰還電流がモジュールのGND端子を通ります。そのネジが高抵抗になると、数アンペアが電源のマイナスへ戻る別経路を探し、利用できるのは信号線だけ — つまりGPIOへ直接流れ込みます。焼損したGPIO5とGPIO19に最もよく合致する説明です。伝導性で、アンペア級で、ポンプ起動時にちょうど発生します。

**ガルバニック絶縁が保たれていれば、その電流がESP32へ至る経路は存在しません。** モジュールを取り外した状態で、制御側GNDと負荷側GNDの間をテスターの抵抗モードで測定してください。

- **開放** — 本物の絶縁です。この状態を維持し、両GNDをどこでも接続しないでください。
- **約0 Ω** — GND共通です。はんだジャンパを探してください。切断すれば保護が回復します。

### フォトカプラ経由のPWM

`FertManager` はチャンネル1〜5でLEDCを5 kHzで駆動します。一般的なフォトカプラ（PC817など）はオンよりオフがかなり遅いため、ゲートに届くデューティは指令値と正確には一致せず、特に低デューティで差が出ます。流量キャリブレーションは実測なのでこれを吸収しますが、低PWMでチャンネルが回らない場合の原因はこれであり、ポンプの非力さではありません。

---

## 📊 数量サマリー

| カテゴリ | 数量 |
|---|---|
| 電解コンデンサ | 6–10 |
| ダイオード（フライバック） | 8 |
| 抵抗 | 1 |
| モーター/ポンプ | 7 |
| センサー | 4 |
| モジュール（ESP32、LM2596、MOSFET、リレー、RTC、TFT） | 6 |

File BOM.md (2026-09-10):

# BOM — Bill of Materials

Lista completa de componentes do sistema IARA.

---

## 🧠 Controlador

| # | Componente | Especificação | Qtd |
|---|---|---|---|
| 1 | ESP32 DevKit V1 | 38 pinos, WROOM-32 | 1 |

---

## ⚡ Camada 1 — Entrada AC e Proteção

| # | Componente | Especificação | Qtd |
|---|---|---|---|
| 2 | Conector IEC C14 | Macho painel com fusível | 1 |
| 3 | Fusível AC | 3A–5A, 250V | 1 |
| 4 | NTC 5D-11 | Limitador inrush, 5Ω a frio | 1 |
| 5 | Capacitor NDF 222M | Capacitor Y, Fase–Terra | 1 |
| 6 | Capacitor NDF 222M | Capacitor Y, Neutro–Terra | 1 |
| 7 | Módulo Relé SSR 1CH | SSR, controle do Canister (AC) | 1 |

---

## 🔋 Camada 2 — Barramento DC e Lógica

| # | Componente | Especificação | Qtd |
|---|---|---|---|
| 8 | Fonte Colmeia 180W | 12V (ajustada 12.53V) | 1 |
| 9 | Fusível T5AL250V | 5A, proteção DC | 1 |
| 10 | Módulo LM2596 | Step-down ajustável (→ 5.1V) | 1 |
| 11 | Módulo MOSFET 8 canais | Entrada optoacoplada, **versão 3,3 V**, PWM em todos os canais, 12V. MOSFET não identificado — ver nota abaixo | 1 |
| 12 | Capacitor eletrolítico 470µF | 16V, filtro entrada MOSFET | 1 |
| 13 | Capacitor eletrolítico 1000µF | 10V — 4 no barramento 5V, 1 direto nos pinos 3V3/GND da devkit (ver `HARDWARE.md`) | 5 |

---

## 🌊 Camada 3 — Atuadores

| # | Componente | Especificação | Qtd |
|---|---|---|---|
| 14 | Bomba peristáltica 12V | Fertilizantes (CH1–CH4) | 4 |
| 15 | Bomba peristáltica 12V | Prime / desclorificante (CH5) | 1 |
| 16 | Bomba submersível 12V | Esgoto / drenagem (CH6) | 1 |
| 17 | Bomba submersível 12V | Recalque / refill (CH7) | 1 |
| 18 | Válvula solenoide 12V | Normalmente fechada (CH8) | 1 |
| 19 | Filtro canister | Controlado via relé AC | 1 |

---

## 📡 Sensores

| # | Componente | Especificação | Qtd |
|---|---|---|---|
| 20 | A02YYUW | Ultrassônico à prova d'água, UART, **3.3V** | 1 |
| 21 | Reed switch + ímã | Trava de nível máx., NA, em série GPIO33→IN7 | 1 |
| 22 | Boia float switch | Nível do reservatório (GPIO 19) | 1 |
| 23 | DS3231 | Módulo RTC I2C (SDA 21 / SCL 22) | 1 |
| 24 | Display TFT 1.8" | ST7735, SPI, 128×160 | 1 |
| 24b| Botão Push/Tactile | Navegação do display (GPIO 0) | 1 |

---

## 🛡️ Proteção e Filtragem

| # | Componente | Especificação | Qtd |
|---|---|---|---|
| 25 | Diodo FR154 | Fast Recovery, flyback bombas | 7 |
| 26 | Diodo 1N5822 | Schottky, flyback solenoide | 1 |
| 27 | Resistor 10kΩ | ¼W, pull-up do GPIO34 (TX do A02YYUW) | 1 |
| 28 | Capacitor 10µF / 22µF | 50V, desacoplamento sensores | 2–4 |

---

## 🔌 Conectores e Acessórios

| # | Componente | Especificação | Qtd |
|---|---|---|---|
| 29 | Conector GX12 (Aviação) | Painel fêmea/macho, para sensores | 2–4 |
| 30 | Cabo blindado multi-vias | 4 a 5 vias, soldável no GX12, 1.2m | 2–4 |
| 31 | Borne KRE / Wago | Conexões de potência | ~20 |
| 32 | Espaguete termo-retrátil | Isolamento NTC e soldas | 1m |
| 33 | Fio 22 AWG | Sinal / sensores | ~5m |
| 34 | Fio 18 AWG | Potência / bombas | ~10m |

---

## 📝 Notas sobre o módulo MOSFET

O módulo em uso é um **8 canais com entrada optoacoplada, versão 3,3 V**, com PWM em todos os canais. Anúncio: item AliExpress `1005010404945969`.

**O part number do MOSFET não está confirmado.** A BOM dizia `IRF540N ou equivalente`, o que era palpite — e um palpite ruim: o IRF540N tem V<sub>GS(th)</sub> de 2,0–4,0 V e é especificado para R<sub>DS(on)</sub> com V<sub>GS</sub> = 10 V. Se fosse mesmo IRF540N num gate de 3,3 V, ele operaria na região linear, dissipando watts num TO-220 sem dissipador dentro de uma caixa fechada. O módulo funciona, então provavelmente **não** é IRF540N. Leia a marcação gravada no encapsulamento e registre aqui — quem repuser um canal queimado vai comprar pelo que estiver escrito neste arquivo.

### Por que este módulo dispensa pull-down nas entradas

Numa placa de acionamento direto, o terminal IN vai ao **gate** do MOSFET. Gate é capacitivo e não tem limiar: tensão parasita acumula carga e o transistor começa a conduzir. Por isso essas placas exigem um pull-down de 10 kΩ em cada entrada — sem ele, o GPIO13 e o GPIO14 do ESP32, que saem do reset com pull-up interno de ~45 kΩ, poderiam ligar bombas durante os ~300 ms de bootloader, a cada reset e a cada gravação.

Aqui o IN alimenta um **LED** dentro do optoacoplador, e LED é dispositivo de limiar — precisa de 5 a 20 mA para acender. O pull-up interno entrega no máximo `(3,3 − 1,2) / 45k ≈ 47 µA`, duas a três ordens de grandeza abaixo disso. **O optoacoplador já cumpre o papel do pull-down.**

Confirme com o multímetro em **modo diodo**, entre IN e o GND do lado de controle: ~1,0–1,3 V numa polaridade e aberto na outra significa LED. Se ler resistência nos dois sentidos, é acionamento direto e os pull-downs voltam a ser obrigatórios.

### Verifique se o isolamento é real

Placas baratas anunciadas "com optoacoplador" frequentemente unem os dois GNDs por um jumper de solda ou uma trilha, e aí a barreira é decorativa.

Isso importa muito neste projeto. Todos os 8 canais chaveiam pelo lado baixo, então a corrente de retorno de todas as bombas passa pelo terminal GND do módulo. Se esse parafuso afrouxar, vários ampères procuram outro caminho de volta ao negativo da fonte — e o único disponível são os fios de sinal, entrando direto nos GPIOs. É a explicação que melhor encaixa com os GPIO5 e GPIO19 queimados: é conduzida, é ampères, e acontece exatamente quando uma bomba parte.

**Com a barreira galvânica intacta essa corrente não tem caminho até o ESP32.** Meça com o ohmímetro, módulo desconectado, entre o GND do lado de controle e o GND do lado de potência:

- **Aberto** — isolamento real. Mantenha assim: não una esses dois GNDs em lugar nenhum.
- **~0 Ω** — GNDs compartilhados. Procure o jumper de solda; cortá-lo devolve a proteção.

### PWM através do optoacoplador

`FertManager` roda LEDC a 5 kHz nos canais 1 a 5. Um optoacoplador comum (PC817 e similares) desliga bem mais devagar do que liga, então o duty que chega ao gate não é exatamente o comandado, sobretudo em valores baixos. A calibração de vazão absorve isso, porque é medida empiricamente — mas se um canal não girar em PWM baixo, a causa é essa, não bomba fraca.

---

## 📊 Resumo de Quantidades

| Categoria | Itens |
|---|---|
| Capacitores eletrolíticos | 6–10 |
| Diodos (flyback) | 8 |
| Resistores | 1 |
| Motores / bombas | 7 |
| Sensores | 4 |
| Módulos (ESP32, LM2596, MOSFET, Relé, RTC, TFT) | 6 |

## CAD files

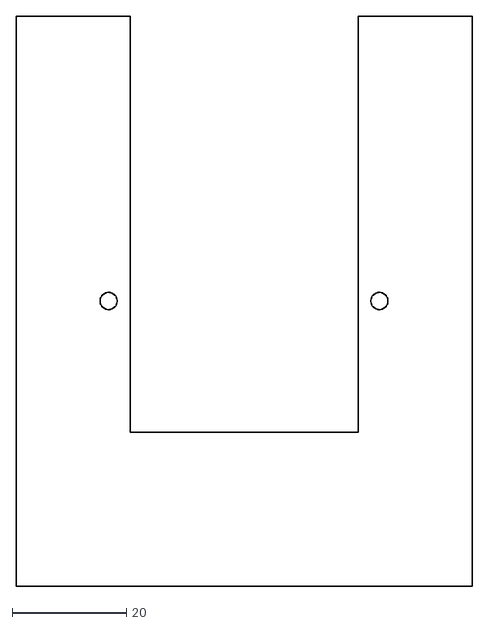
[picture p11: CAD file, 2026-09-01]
3d_models/pump_shelf_test.dxf
80.0 x 100.0

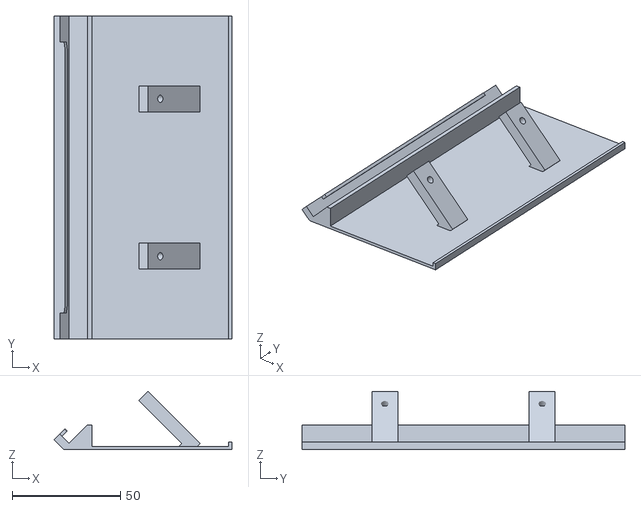
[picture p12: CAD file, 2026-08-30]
3d_models/chihiros-shades-sensor.stl
82.1 x 149.0 x 26.9

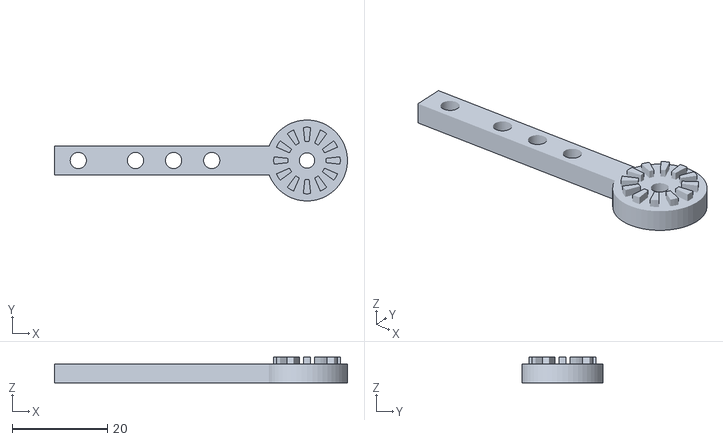
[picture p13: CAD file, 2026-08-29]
3d_models/reed_seesaw_arm_float.stl
61.5 x 17.0 x 5.40

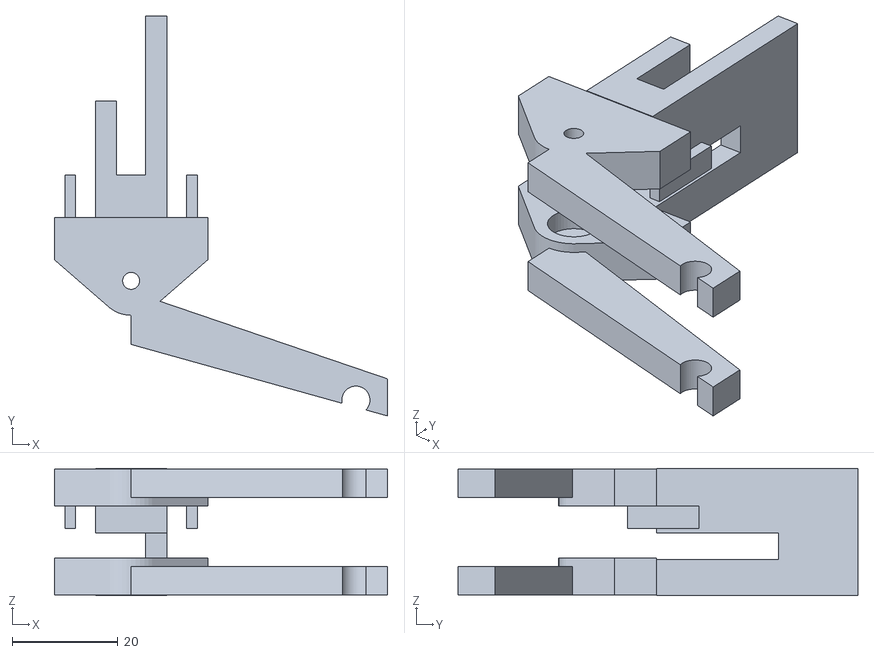
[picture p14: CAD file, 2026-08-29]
3d_models/reed_seesaw_bracket.stl
62.9 x 75.5 x 24.0

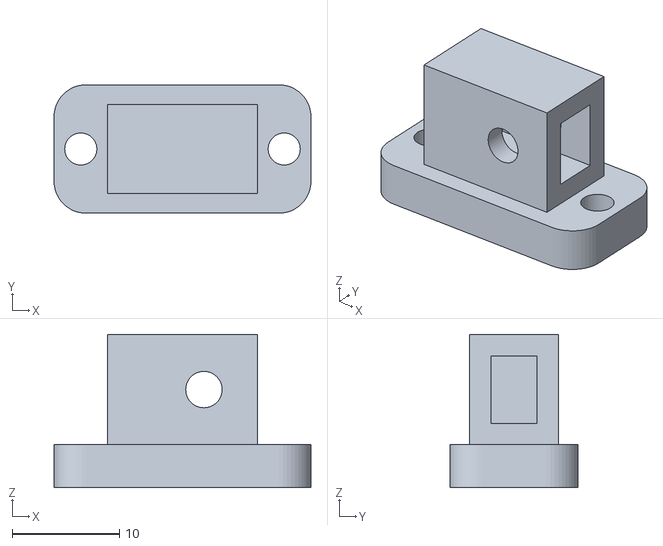
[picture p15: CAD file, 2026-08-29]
3d_models/reed_seesaw_float_tray.stl
24.0 x 12.0 x 14.3

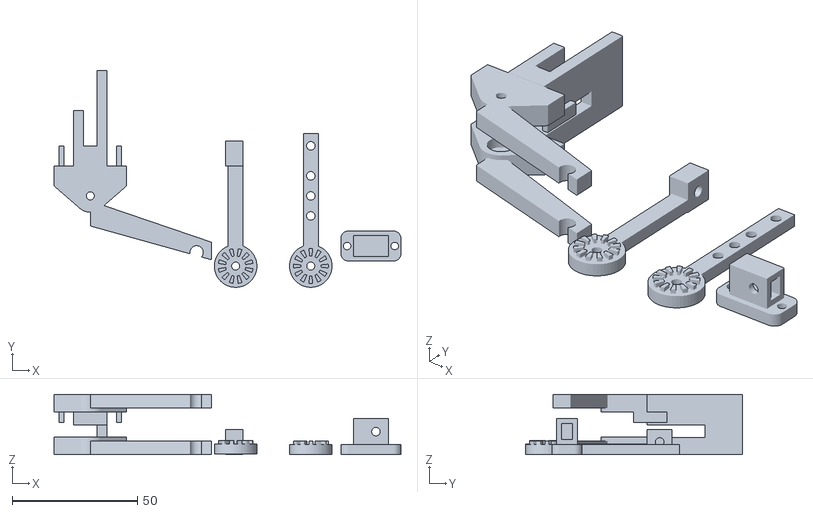
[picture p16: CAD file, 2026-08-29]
3d_models/reed_seesaw_mesa.stl
138.5 x 86.5 x 24.0

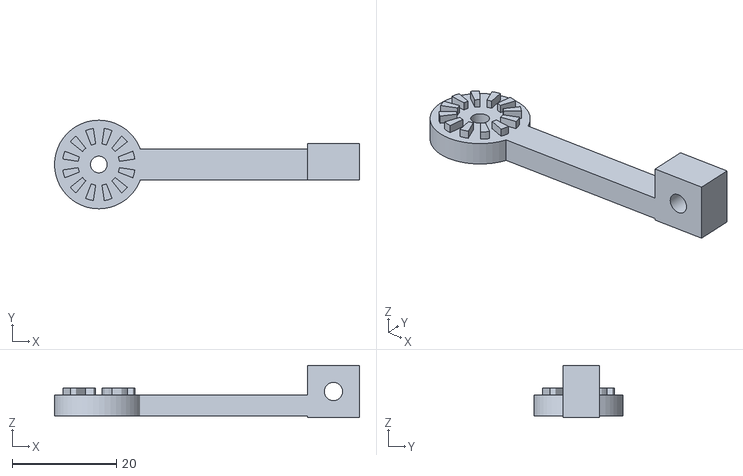
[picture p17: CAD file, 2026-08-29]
3d_models/reed_seesaw_arm_mag.stl
58.5 x 17.0 x 10.0

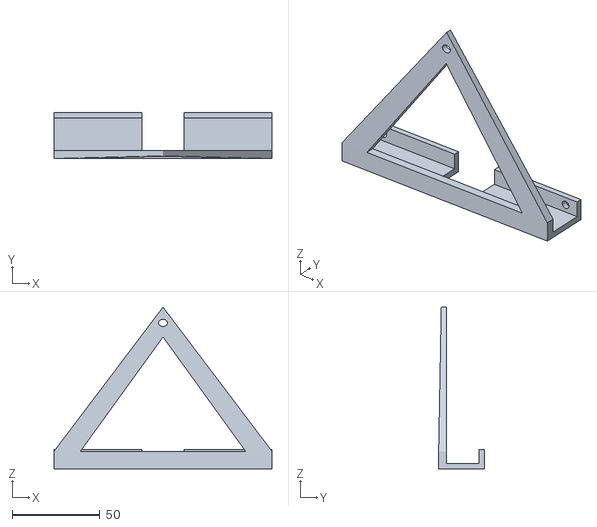
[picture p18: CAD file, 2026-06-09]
3d_models/chihiros_support_final.stl
124.0 x 26.0 x 92.0

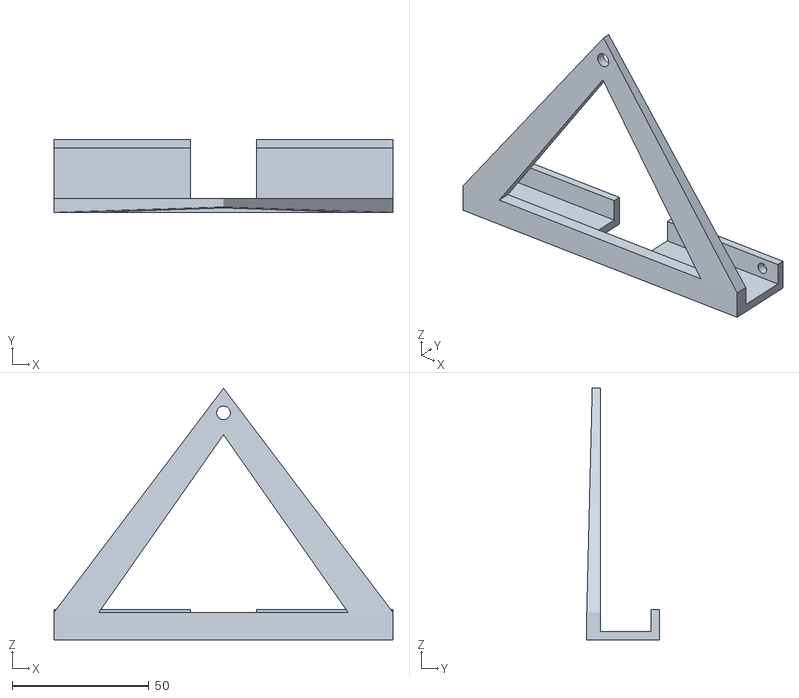
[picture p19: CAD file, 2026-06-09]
3d_models/chihiros_support_solid.stl
124.0 x 26.5 x 92.0

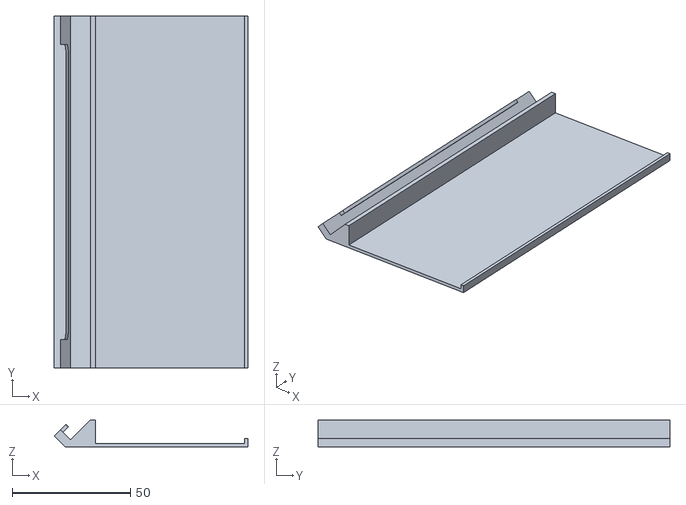
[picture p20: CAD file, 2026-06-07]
3d_models/chihiros-shades.stl
82.1 x 149.0 x 11.4

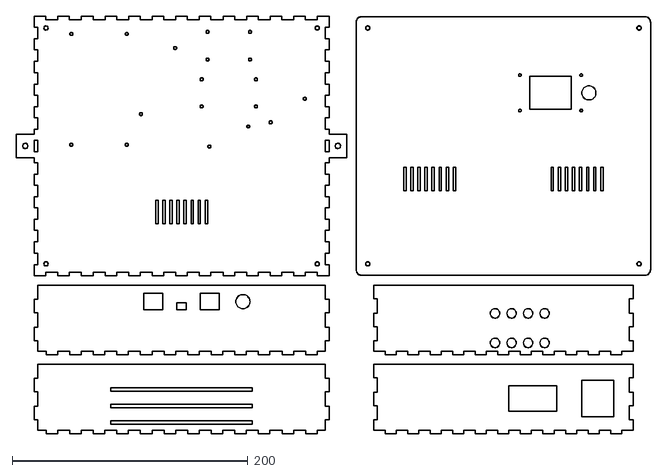
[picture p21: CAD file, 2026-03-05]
3d_models/electronics_enclosure_laser.dxf
537.5 x 354.0

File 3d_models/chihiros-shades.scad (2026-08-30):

// Arquivo gerado automaticamente
// =========================================================
// MODO DE VISUALIZAÇÃO E IMPRESSÃO
// =========================================================
modo_impressao = true; // true = Sólido de impressão limpo, false = Wireframe de debug
comprimento = 150; // Comprimento total da peça em mm (ex: 300 = 30cm, 200 = 20cm)

// =========================================================
// ENCAIXE DO SENSOR ULTRASSONICO
// =========================================================
// Dois bracos em L, um sob cada orelha do A02YYUW. A CHAPA DA SHADE
// FICA INTACTA: nada de janela, nada de furo nela.
//
// Cada L tem duas pernas, e a diferenca entre elas e o ponto do
// projeto:
//
//   * o BRACO fica NO PRUMO, alinhado com o eixo da aba do clipe. Nao
//     e perpendicular a chapa. A base dele sai cortada em bisel onde
//     encontra a chapa, porque ela esta a 45 graus.
//   * o PE e perpendicular ao braco, 90 graus, e por isso fica
//     nivelado. E nele que o sensor aparafusa.
//
// Braco no prumo com pe a 90 graus e a unica combinacao que da, ao
// mesmo tempo, canto vivo, assento nivelado e impressao sem balanco.
// Braco perpendicular a chapa obrigaria o pe a dobrar 45 graus.
//
// POR QUE O ASSENTO PRECISA ESTAR NIVELADO
// Transdutor fora do prumo manda o eco embora: a onda bate na agua em
// angulo e volta desviada. O A02YYUW le errado ou nao le nada. Um
// assento paralelo a chapa deixaria o sensor a 45 graus.
//
// O FURO FICA NO PE, NA PERNA FINA
// Ele atravessa so a espessura do pe, e a porca aperta na face de
// baixo dele -- paralela ao assento, entao a porca assenta reta. Furo
// no canto obrigaria o parafuso a descer pelo braco e sair oblique-
// mente do outro lado, com a porca apoiada numa aresta.
//
// O PE E ASSIMETRICO EM VOLTA DO FURO
// Alongar so a frente empurra o braco rampa abaixo sem tirar o furo do
// lugar: o braco desce no prumo contra uma chapa que cai 45 graus,
// entao encontra a chapa mais cedo e fica curto sozinho.
//
// DE ONDE SAI O ANGULO
// Da ABA DO CLIPE (rosa), a peca reta que entra na luminaria num rasgo
// em pe: o eixo LONGO dela e a vertical do mundo. Vem dos proprios
// pontos do perfil, Black (1.5858, 5.5355) ate Navy (5.4749, 9.4246):
// 3,889 em x para 3,889 em z, ou seja 45 graus. Nao e constante fixa;
// se o perfil mudar, o assento acompanha.
//
// Cuidado com a rampa (Olive->Black): ela esta a 135 graus, PERPEN-
// DICULAR a aba. Usar a rampa como referencia inclina o assento para o
// lado errado.
function aba_dx() = 5.4749 - 1.5858;
function aba_dz() = 9.4246 - 5.5355;
function sensor_ang() = atan2(aba_dz(), aba_dx());

// Centro da chapa livre, entre a parede interna e o labio do acrilico
function x_sensor() = (17.1213 + 80.2426)/2;

sensor_montar   = true;
sensor_lado     = 1;     // +1 face de cima da chapa, -1 face de baixo
sensor_sentido  = 1;     // de que lado a aba aponta para cima
sensor_braco_lado = 1;   // de que ponta do pe o braco sai: -1 atras, +1 frente
sensor_y        = 75;    // centro do sensor ao longo da peca
sensor_furos    = 72.6;  // entre-eixos dos furos das orelhas

// Largura e espessura sao coisas diferentes e nao podem cair juntas: o
// furo M3 atravessa a ESPESSURA, e e a LARGURA que deixa material em
// volta dele. A 6 mm de largura sobrariam 1,3 mm de parede de cada
// lado do furo, que rasga no aperto.
sensor_haste    = 12;    // largura, transversal a peca
sensor_esp      = 6;     // espessura, no sentido do L
sensor_haste_h  = 30;    // comprimento maximo do braco, antes do bisel
sensor_pe_tras   = 8;    // pe, do furo para tras
sensor_pe_frente = 26;   // pe, do furo para a frente
sensor_furo_d   = 3.4;   // furo passante para M3

y_ini = 0.5;
y_fim = comprimento - 0.5;
y_clip_ini = 12.5; // Início da transição do clipe (fixo, perto da borda)
y_clip_fim = comprimento - 12.5; // Fim da transição do clipe (espelhado)
y_clip_reto_ini = 15.5; // Início do miolo reto do clipe
y_clip_reto_fim = comprimento - 15.5; // Fim do miolo reto do clipe

pontos = [
  // [0, 1] Ponta esquerda extrema (Vermelho)
  [0.4216, y_ini, 4.3713],
  [0.4216, y_fim, 4.3713],
  // [2, 3] Base interna (Verde)
  [4.2929, y_ini, 0.5000],
  [4.2929, y_fim, 0.5000],
  // [4, 5] Base externa (Azul)
  [81.7426, y_ini, 0.5000],
  [81.7426, y_fim, 0.5000],
  // [6, 7] Lábio externo topo (Amarelo)
  [81.7426, y_ini, 2.0000],
  [81.7426, y_fim, 2.0000],
  // [8, 9] Lábio externo base (Magenta)
  [80.2426, y_ini, 2.0000],
  [80.2426, y_fim, 2.0000],
  // [10, 11] Chanfro externo topo (Azul Claro / Cyan)
  [78.2071, y_ini, 5.5355],
  [78.2071, y_fim, 5.5355],
  // [12, 13] Chanfro externo plano (Laranja)
  [76.7071, y_ini, 5.5355],
  [76.7071, y_fim, 5.5355],
  // [14, 15] Parede vertical base (Roxo)
  [17.1213, y_ini, 2.0000],
  [17.1213, y_fim, 2.0000],
  // [16, 17] Parede vertical topo (exterior) (Marrom)
  [17.1213, y_ini, 11.8787],
  [17.1213, y_fim, 11.8787],
  // [18, 19] Parede vertical topo (interior / início da rampa) (Pink)
  [15.0000, y_ini, 11.8787],
  [15.0000, y_fim, 11.8787],
  // [20, 21] Clip face de encaixe (base do dente) (Lime)
  [6.5355, y_clip_reto_ini, 8.3640],
  [6.5355, y_clip_reto_fim, 8.3640],
  // [22, 23] Clip face de encaixe (topo do dente) (Navy)
  [5.4749, y_clip_reto_ini, 9.4246],
  [5.4749, y_clip_reto_fim, 9.4246],
  // [24, 25] Transição do Clip (Gold)
  [4.5910, y_clip_ini, 6.4194],
  [4.5910, y_clip_fim, 6.4194],
  // [26, 27] Transição do Clip (Teal)
  [3.5303, y_clip_ini, 7.4801],
  [3.5303, y_clip_fim, 7.4801],
  // [28, 29] Transição do Clip (Maroon)
  [2.6464, y_clip_ini, 4.4749],
  [2.6464, y_clip_fim, 4.4749],
  // [30, 31] Pé da rampa (Olive)
  [5.1213, y_ini, 2.0000],
  [5.1213, y_fim, 2.0000],
  // [32, 33, 34, 35] Chanfro interno topo (Black)
  [1.5858, y_ini, 5.5355],
  [1.5858, y_clip_ini, 5.5355],
  [1.5858, y_clip_fim, 5.5355],
  [1.5858, y_fim, 5.5355],

  // NOVOS PONTOS PARA A CAVA DO ACRÍLICO (PAREDE DIREITA RETA)
  // [36, 37] Parede Direita - Topo Externo
  [81.7426, y_ini, 4.0000],
  [81.7426, y_fim, 4.0000],
  // [38, 39] Parede Direita - Topo Interno
  [80.2426, y_ini, 4.0000],
  [80.2426, y_fim, 4.0000],
];

// =========================================================
// DEFINIÇÃO DE MÓDULOS (OpenSCAD exige que módulos fiquem fora de if/else)
// =========================================================

module objeto_final_impressao(tol_clip = 0, aumento_diag = 0, aumento_rampa = 0, cor_corpo = "LightGray", cor_clipe = "HotPink") {
  function aplicar_tolerancia(p, t) =
    [
      [p[0][0] + t * 0.7071, p[0][1] - t * 0.7071], // Maroon 
      p[1], // Black 
      p[2], // Navy/Teal 
      [p[3][0] + t * 0.7071, p[3][1] - t * 0.7071], // Lime/Gold 
    ];

  module cunha_transicao(y_start, y_end, p1, p2) {
    hull() {
      translate([0, y_start, 0]) rotate([90, 0, 0]) linear_extrude(0.01) polygon(aplicar_tolerancia(p1, tol_clip));
      translate([0, y_end, 0]) rotate([90, 0, 0]) linear_extrude(0.01) polygon(aplicar_tolerancia(p2, tol_clip));
    }
  }

  // Centro da chapa livre, entre a parede interna e o labio do acrilico
  x_sensor = (17.1213 + 80.2426)/2;

  translate([0, 0, -0.5])
    difference() {
    union() {
      // 1. CORPO PRINCIPAL (Extrusão do perfil frontal)
      // O retângulo base é esticado e engrossado movendo Red e Black na diagonal
      perfil_xy = [
        [pontos[0][0] - aumento_diag, pontos[0][2] + aumento_diag], // 0: Red
        [pontos[2][0], pontos[2][2]], // 2: Green (fixo)
        [pontos[4][0], pontos[4][2]], // 4: Blue
        [pontos[36][0], pontos[36][2]], // 36: Parede dir topo ext 
        [pontos[38][0], pontos[38][2]], // 38: Parede dir topo int 
        [pontos[8][0], pontos[8][2]], // 8: Magenta 
        [pontos[14][0], pontos[14][2]], // 14: Purple 
        [pontos[16][0], pontos[16][2]], // 16: Brown 
        [pontos[18][0], pontos[18][2]], // 18: Pink
        [pontos[30][0] + aumento_rampa, pontos[30][2] + aumento_rampa], // 30: Olive (Move na diagonal oposta para engrossar a rampa)
        [pontos[32][0] - aumento_diag + aumento_rampa, pontos[32][2] + aumento_diag + aumento_rampa], // 32: Black (Soma os dois movimentos)
      ];

      color(cor_corpo) {
        translate([0, y_fim, 0]) rotate([90, 0, 0]) linear_extrude(height=y_fim - y_ini) polygon(perfil_xy);
      }

      // 2. O CLIPE
      // O topo do clipe (Navy, Lime) acompanha apenas o alargamento base (aumento_diag)
      // O buraco e a base (Maroon, Black, Teal, Gold) acompanham também a rampa (aumento_rampa)
      // Isso encurta o clipe em exatos `aumento_rampa`!

      dx_base = -aumento_diag + aumento_rampa;
      dz_base = aumento_diag + aumento_rampa;

      dx_topo = -aumento_diag;
      dz_topo = aumento_diag;
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

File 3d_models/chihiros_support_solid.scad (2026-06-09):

meus_pontos = [[68.5438, 48.9848, 10.0], [68.5438, 49.0098, 0.0], [68.5438, 53.4848, 10.0], [68.5438, 53.5098, 3.0], [68.5438, 72.0098, 3.0], [68.5438, 72.0098, 11.0], [68.5438, 75.0098, 0.0], [68.5438, 75.0098, 11.0], [73.5408, 72.0098, 7.0], [73.5408, 75.0098, 7.0], [73.5588, 72.0098, 6.739], [73.5588, 72.0098, 7.261], [73.5588, 75.0098, 6.739], [73.5588, 75.0098, 7.261], [73.6098, 72.0098, 6.482], [73.6098, 72.0098, 7.518], [73.6098, 75.0098, 6.482], [73.6098, 75.0098, 7.518], [73.6938, 72.0098, 6.234], [73.6938, 72.0098, 7.766], [73.6938, 75.0098, 6.234], [73.6938, 75.0098, 7.766], [73.8098, 72.0098, 5.999], [73.8098, 72.0098, 8.001], [73.8098, 75.0098, 5.999], [73.8098, 75.0098, 8.001], [73.9548, 72.0098, 5.781], [73.9548, 72.0098, 8.219], [73.9548, 75.0098, 5.781], [73.9548, 75.0098, 8.219], [74.1278, 72.0098, 5.584], [74.1278, 72.0098, 8.416], [74.1278, 75.0098, 5.584], [74.1278, 75.0098, 8.416], [74.3248, 72.0098, 5.411], [74.3248, 72.0098, 8.589], [74.3248, 75.0098, 5.411], [74.3248, 75.0098, 8.589], [74.5428, 72.0098, 5.266], [74.5428, 72.0098, 8.734], [74.5428, 75.0098, 5.266], [74.5428, 75.0098, 8.734], [74.7778, 72.0098, 5.15], [74.7778, 72.0098, 8.85], [74.7778, 75.0098, 5.15], [74.7778, 75.0098, 8.85], [75.0258, 72.0098, 5.066], [75.0258, 72.0098, 8.934], [75.0258, 75.0098, 5.066], [75.0258, 75.0098, 8.934], [75.2828, 72.0098, 5.015], [75.2828, 72.0098, 8.985], [75.2828, 75.0098, 5.015], [75.2828, 75.0098, 8.985], [75.5438, 72.0098, 4.998], [75.5438, 72.0098, 9.003], [75.5438, 75.0098, 4.998], [75.5438, 75.0098, 9.003], [75.8048, 72.0098, 5.015], [75.8048, 72.0098, 8.985], [75.8048, 75.0098, 5.015], [75.8048, 75.0098, 8.985], [76.0618, 72.0098, 5.066], [76.0618, 72.0098, 8.934], [76.0618, 75.0098, 5.066], [76.0618, 75.0098, 8.934], [76.3098, 72.0098, 5.15], [76.3098, 72.0098, 8.85], [76.3098, 75.0098, 5.15], [76.3098, 75.0098, 8.85], [76.5448, 72.0098, 5.266], [76.5448, 72.0098, 8.734], [76.5448, 75.0098, 5.266], [76.5448, 75.0098, 8.734], [76.7628, 72.0098, 5.411], [76.7628, 72.0098, 8.589], [76.7628, 75.0098, 5.411], [76.7628, 75.0098, 8.589], [76.9598, 72.0098, 5.584], [76.9598, 72.0098, 8.416], [76.9598, 75.0098, 5.584], [76.9598, 75.0098, 8.416], [77.1328, 72.0098, 5.781], [77.1328, 72.0098, 8.219], [77.1328, 75.0098, 5.781], [77.1328, 75.0098, 8.219], [77.2778, 72.0098, 5.999], [77.2778, 72.0098, 8.001], [77.2778, 75.0098, 5.999], [77.2778, 75.0098, 8.001], [77.3938, 72.0098, 6.234], [77.3938, 72.0098, 7.766], [77.3938, 75.0098, 6.234], [77.3938, 75.0098, 7.766], [77.4778, 72.0098, 6.482], [77.4778, 72.0098, 7.518], [77.4778, 75.0098, 6.482], [77.4778, 75.0098, 7.518], [77.5288, 72.0098, 6.739], [77.5288, 72.0098, 7.261], [77.5288, 75.0098, 6.739], [77.5288, 75.0098, 7.261], [77.5458, 72.0098, 7.0], [77.5458, 75.0098, 7.0], [83.5408, 49.0098, 9.998], [83.5408, 53.5098, 9.998], [118.5438, 53.5098, 0.0], [118.5438, 53.5098, 3.0], [118.5438, 72.0098, 3.0], [118.5438, 72.0098, 11.0], [118.5438, 75.0098, 0.0], [118.5438, 75.0098, 11.0], [128.0408, 50.3202, 83.0], [128.0408, 53.4848, 83.0], [128.0628, 50.3154, 82.739], [128.0628, 50.3249, 83.261], [128.0628, 53.4848, 82.739], [128.0628, 53.4848, 83.261], [128.1268, 50.3107, 82.482], [128.1268, 50.3296, 83.518], [128.1268, 53.4848, 82.482], [128.1268, 53.4848, 83.518], [128.2318, 50.3062, 82.234], [128.2318, 50.3342, 83.766], [128.2318, 53.4848, 82.234], [128.2318, 53.4848, 83.766], [128.3768, 50.3019, 81.999], [128.3768, 50.3385, 84.001], [128.3768, 53.4848, 81.999], [128.3768, 53.4848, 84.001], [128.5588, 50.2979, 81.781], [128.5588, 50.3425, 84.219], [128.5588, 53.4848, 81.781], [128.5588, 53.4848, 84.219], [128.7738, 50.2943, 81.584], [128.7738, 50.3461, 84.416], [128.7738, 53.4848, 81.584], [128.7738, 53.4848, 84.416], [129.0208, 50.2911, 81.411], [129.0208, 50.3492, 84.589], [129.0208, 53.4848, 81.411], [129.0208, 53.4848, 84.589], [129.2928, 50.2884, 81.266], [129.2928, 50.3519, 84.734], [129.2928, 53.4848, 81.266], [129.2928, 53.4848, 84.734], [129.5858, 50.2863, 81.15], [129.5858, 50.354, 84.85], [129.5858, 53.4848, 81.15], [129.5858, 53.4848, 84.85], [129.8958, 50.2848, 81.066], [129.8958, 50.3555, 84.934], [129.8958, 53.4848, 81.066], [129.8958, 53.4848, 84.934], [130.2168, 50.2839, 81.015], [130.2168, 50.3565, 84.985], [130.2168, 53.4848, 81.015], [130.2168, 53.4848, 84.985], [130.5438, 50.1739, 75.003], [130.5438, 50.2835, 80.998], [130.5438, 50.3568, 85.003], [130.5438, 50.4848, 92.0], [130.5438, 53.4848, 75.003], [130.5438, 53.4848, 80.998], [130.5438, 53.4848, 85.003], [130.5438, 53.4848, 92.0], [130.8708, 50.2839, 81.015], [130.8708, 50.3565, 84.985], [130.8708, 53.4848, 81.015], [130.8708, 53.4848, 84.985], [131.1918, 50.2848, 81.066], [131.1918, 50.3555, 84.934], [131.1918, 53.4848, 81.066], [131.1918, 53.4848, 84.934], [131.5018, 50.2863, 81.15], [131.5018, 50.354, 84.85], [131.5018, 53.4848, 81.15], [131.5018, 53.4848, 84.85], [131.7948, 50.2884, 81.266], [131.7948, 50.3519, 84.734], [131.7948, 53.4848, 81.266], [131.7948, 53.4848, 84.734], [132.0668, 50.2911, 81.411], [132.0668, 50.3492, 84.589], [132.0668, 53.4848, 81.411], [132.0668, 53.4848, 84.589], [132.3138, 50.2943, 81.584], [132.3138, 50.3461, 84.416], [132.3138, 53.4848, 81.584], [132.3138, 53.4848, 84.416], [132.5288, 50.2979, 81.781], [132.5288, 50.3425, 84.219], [132.5288, 53.4848, 81.781], [132.5288, 53.4848, 84.219], [132.7108, 50.3019, 81.999], [132.7108, 50.3385, 84.001], [132.7108, 53.4848, 81.999], [132.7108, 53.4848, 84.001], [132.8558, 50.3062, 82.234], [132.8558, 50.3342, 83.766], [132.8558, 53.4848, 82.234], [132.8558, 53.4848, 83.766], [132.9608, 50.3107, 82.482], [132.9608, 50.3296, 83.518], [132.9608, 53.4848, 82.482], [132.9608, 53.4848, 83.518], [133.0248, 50.3154, 82.739], [133.0248, 50.3249, 83.261], [133.0248, 53.4848, 82.739], [133.0248, 53.4848, 83.261], [133.0468, 50.3202, 83.0], [133.0468, 53.4848, 83.0], [142.5438, 53.5098, 0.0], [142.5438, 53.5098, 3.0], [142.5438, 72.0098, 3.0], [142.5438, 72.0098, 11.0], [142.5438, 75.0098, 0.0], [142.5438, 75.0098, 11.0], [177.5453, 48.9848, 10.0], [177.5453, 53.4848, 10.0], [183.5418, 72.0098, 3.0], [183.5418, 72.0098, 7.0], [183.5418, 75.0098, 7.0], [183.5588, 72.0098, 6.739], [183.5588, 72.0098, 7.261], [183.5588, 75.0098, 6.739], [183.5588, 75.0098, 7.261], [183.6098, 72.0098, 6.482], [183.6098, 72.0098, 7.518], [183.6098, 75.0098, 6.482], [183.6098, 75.0098, 7.518], [183.6938, 72.0098, 6.234], [183.6938, 72.0098, 7.766], [183.6938, 75.0098, 6.234], [183.6938, 75.0098, 7.766], [183.8098, 72.0098, 5.999], [183.8098, 72.0098, 8.001], [183.8098, 75.0098, 5.999], [183.8098, 75.0098, 8.001], [183.9548, 72.0098, 5.781], [183.9548, 72.0098, 8.219], [183.9548, 75.0098, 5.781], [183.9548, 75.0098, 8.219], [184.1278, 72.0098, 5.584], [184.1278, 72.0098, 8.416], [184.1278, 75.0098, 5.584], [184.1278, 75.0098, 8.416], [184.3248, 72.0098, 5.411], [184.3248, 72.0098, 8.589], [184.3248, 75.0098, 5.411], [184.3248, 75.0098, 8.589], [184.5428, 72.0098, 5.266], [184.5428, 72.0098, 8.734], [184.5428, 75.0098, 5.266], [184.5428, 75.0098, 8.734], [184.7778, 72.0098, 5.15], [184.7778, 72.0098, 8.85], [184.7778, 75.0098, 5.15], [184.7778, 75.0098, 8.85], [185.0258, 72.0098, 5.066], [185.0258, 72.0098, 8.934], [185.0258, 75.0098, 5.066], [185.0258, 75.0098, 8.934], [185.2828, 72.0098, 5.015], [185.2828, 72.0098, 8.985], [185.2828, 75.0098, 5.015], [185.2828, 75.0098, 8.985], [185.5438, 72.0098, 4.998], [185.5438, 72.0098, 9.003], [185.5438, 75.0098, 4.998], [185.5438, 75.0098, 9.003], [185.8048, 72.0098, 5.015], [185.8048, 72.0098, 8.985], [185.8048, 75.0098, 5.015], [185.8048, 75.0098, 8.985], [186.0618, 72.0098, 5.066], [186.0618, 72.0098, 8.934], [186.0618, 75.0098, 5.066], [186.0618, 75.0098, 8.934], [186.3098, 72.0098, 5.15], [186.3098, 72.0098, 8.85], [186.3098, 75.0098, 5.15], [186.3098, 75.0098, 8.85], [186.5448, 72.0098, 5.266], [186.5448, 72.0098, 8.734], [186.5448, 75.0098, 5.266], [186.5448, 75.0098, 8.734], [186.7628, 72.0098, 5.411], [186.7628, 72.0098, 8.589], [186.7628, 75.0098, 5.411], [186.7628, 75.0098, 8.589], [186.9598, 72.0098, 5.584], [186.9598, 72.0098, 8.416], [186.9598, 75.0098, 5.584], [186.9598, 75.0098, 8.416], [187.1328, 72.0098, 5.781], [187.1328, 72.0098, 8.219], [187.1328, 75.0098, 5.781], [187.1328, 75.0098, 8.219], [187.2778, 72.0098, 5.999], [187.2778, 72.0098, 8.001], [187.2778, 75.0098, 5.999], [187.2778, 75.0098, 8.001], [187.3938, 72.0098, 6.234], [187.3938, 72.0098, 7.766], [187.3938, 75.0098, 6.234], [187.3938, 75.0098, 7.766], [187.4778, 72.0098, 6.482], [187.4778, 72.0098, 7.518], [187.4778, 75.0098, 6.482], [187.4778, 75.0098, 7.518], [187.5288, 72.0098, 6.739], [187.5288, 72.0098, 7.261], [187.5288, 75.0098, 6.739], [187.5288, 75.0098, 7.261], [187.5468, 72.0098, 7.0], [187.5468, 75.0098, 7.0], [192.5438, 48.9848, 10.0], [192.5438, 49.0098, 0.0], [192.5438, 53.4848, 10.0], [192.5438, 53.5098, 3.0], [192.5438, 72.0098, 3.0], [192.5438, 72.0098, 11.0], [192.5438, 75.0098, 0.0], [192.5438, 75.0098,
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

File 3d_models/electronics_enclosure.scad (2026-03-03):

// ============================================================
// IARA - Caixa de Eletrônica (Electronics Enclosure)
// Arquivo: electronics_enclosure.scad
// Descrição: Caixa paramétrica para montagem dos módulos
//            eletrônicos do sistema IARA
// Baseado na Patola PB-710 (130 × 180 × 51mm)
// ============================================================

$fn = 50; // Aumentar para 120+ na exportação STL final

// ============================================================
// PARÂMETROS GERAIS DA CAIXA
// ============================================================

// -- Dimensões externas (baseado na Patola PB-710) --
box_width = 250; // mm (X)
box_depth = 220; // mm (Y) - para fonte 199×98mm + módulos
box_height = 62; // mm (Z) - altura da base (para fonte 42mm)
wall = 3; // mm - espessura das paredes
base_height = 62; // mm - altura da caixa
corner_r = 5; // mm - raio dos cantos arredondados

// -- Tampa de acrílico --
acrylic_thickness = 3; // mm - espessura do acrílico
acrylic_tolerance = 0.5; // mm - folga para encaixe

// -- Furos de fixação da tampa --
screw_d = 3.2; // mm - M3
screw_head_d = 6; // mm - cabeça do parafuso
screw_boss_d = 8; // mm - diâmetro do boss
screw_boss_h = base_height - wall; // mm

// ============================================================
// PARÂMETROS DOS COMPONENTES INTERNOS
// ============================================================

// -- Fonte Colmeia 180W (dimensões reais) --
// 199 x 98 x 42mm
psu_w = 199;
psu_d = 98;
psu_h = 42;

// -- ESP32 DevKit V1 (38 pinos) --
// ~51 x 28mm, furos nos cantos
esp32_w = 51;
esp32_d = 28;
esp32_mount_holes = [[3, 3], [48, 3], [3, 25], [48, 25]];

// -- Módulo MOSFET 8 canais (dimensões reais) --
// PCB: 99 x 52mm, furos: 90 x 43mm, Ø3.2mm
mosfet_w = 99;
mosfet_d = 52;

// -- Módulo LM2596 (dimensões reais) --
// 61 x 34 x 12mm
lm2596_w = 61;
lm2596_d = 34;

// -- Módulo Relé SSR 1CH (dimensões reais) --
// 25mm(L) x 34mm(C) x 21mm(A)
ssr_w = 25;
ssr_d = 34;

// -- DS3231 RTC --
// ~38 x 22mm
rtc_w = 38;
rtc_d = 22;

// -- OLED SSD1306 0.96" 128x64 (dimensões reais) --
// PCB: 27 x 30 x 5mm
oled_screen_w = 25.5; // mm - área visível
oled_screen_h = 14; // mm - área visível
oled_board_w = 27; // mm - PCB largura
oled_board_h = 30; // mm - PCB altura
oled_mount_holes_spacing_w = 23.5; // mm
oled_mount_holes_spacing_h = 23.5; // mm
oled_mount_d = 2.2; // mm - M2

// -- Módulo Sensor Ultrassônico --
// 41 x 28.5mm
ultra_w = 41;
ultra_d = 28.5;

// ============================================================
// PARÂMETROS DOS CONECTORES NO PAINEL
// ============================================================

// -- Entrada AC: Tomada AS-08 IEC C14 com fusível integrado --
// Modelo: AS-08 Tripolar Macho c/ Porta-Fusível (embutir painel)
// Corpo: 31 x 30 x 21.2mm | Recorte painel: ~48 x 28mm
iec_fuse_w = 48; // mm - largura do recorte
iec_fuse_h = 28; // mm - altura do recorte
iec_fuse_mount_w = 40; // mm - distância entre furos de fixação
iec_fuse_mount_d = 3.5; // mm - diâmetro dos furos

// -- Tomada AC Canister: Padrão brasileiro NBR 14136 --
// Tomada fêmea de painel embutida, recorte circular
nbr_outlet_d = 37; // mm - diâmetro do recorte circular
nbr_outlet_mount_spacing = 45; // mm - distância entre furos de fixação
nbr_outlet_mount_d = 3.5; // mm - diâmetro dos furos

// -- Conectores DC para bombas (8x) --
// Conector P4 fêmea de painel (DC barrel jack 5.5x2.1mm)
pump_conn_d = 8; // mm - diâmetro do furo de montagem (P4)
pump_conn_qty = 8;

// -- Conectores RJ45 para sensores --
rj45_w = 16; // mm - largura do recorte
rj45_h = 14; // mm - altura do recorte
rj45_qty = 3; // Ultrassônico, capacitivo, boia

// -- Passagem de cabo (PG7 gland) --
pg7_d = 12; // mm - diâmetro do furo

// -- Cooler 40mm (ventilação MOSFET) --
fan_size = 40; // mm - tamanho do cooler
fan_hole_spacing = 32; // mm - distância entre furos de fixação
fan_screw_d = 3.5; // mm - M3
fan_depth = 10; // mm - espessura do cooler

// -- Ventilação --
vent_slot_w = 2; // mm
vent_slot_l = 20; // mm
vent_spacing = 4; // mm
vent_qty = 8;

// ============================================================
// MÓDULOS
// ============================================================

// --- Forma arredondada da caixa ---
module rounded_box(w, d, h, r) {
  hull() {
    for (x = [-w / 2 + r, w / 2 - r])
      for (y = [-d / 2 + r, d / 2 - r])
        translate([x, y, 0])
          cylinder(r=r, h=h);
  }
}

// --- Boss para parafuso ---
module screw_boss(h, outer_d, inner_d) {
  difference() {
    cylinder(d=outer_d, h=h);
    translate([0, 0, -0.1])
      cylinder(d=inner_d, h=h + 0.2);
  }
}

// --- Standoff para montagem de módulo ---
module standoff(h = 6, outer_d = 4, inner_d = 2.2) {
  difference() {
    cylinder(d=outer_d, h=h);
    translate([0, 0, h - 4])
      cylinder(d=inner_d, h=4.1);
  }
}

// --- Grid de standoffs para um módulo ---
module module_standoffs(w, d, h = 6) {
  inset = 2.5;
  if (w < 40) {
    // Módulos pequenos: apenas 2 standoffs diagonais
    positions = [
      [-w / 2 + inset, -d / 2 + inset],
      [w / 2 - inset, d / 2 - inset],
    ];
    for (pos = positions)
      translate([pos[0], pos[1], 0])
        standoff(h);
  } else {
    // Módulos grandes: 4 standoffs nos cantos
    positions = [
      [-w / 2 + inset, -d / 2 + inset],
      [w / 2 - inset, -d / 2 + inset],
      [-w / 2 + inset, d / 2 - inset],
      [w / 2 - inset, d / 2 - inset],
    ];
    for (pos = positions)
      translate([pos[0], pos[1], 0])
        standoff(h);
  }
}
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

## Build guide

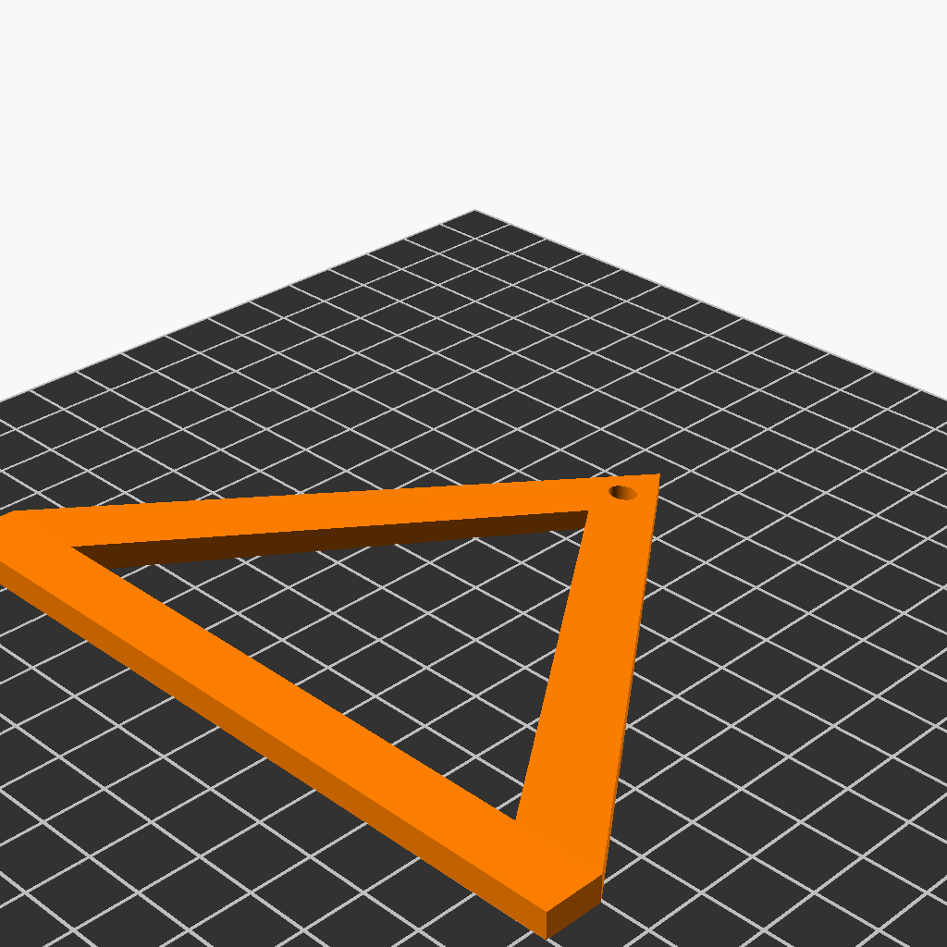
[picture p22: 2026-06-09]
print_orientation.png

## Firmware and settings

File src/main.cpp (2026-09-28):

// =============================================================================
// AQUARIUM AUTOMATION FIRMWARE - ESP32
// =============================================================================
// TPA (Troca Parcial de Água), Fertilization & Filtration Controller
// Priority: Flood prevention and temporal precision
//
// Architecture: OOP with 5 manager classes
//   - SafetyWatchdog: sensor reads, overflow detection, emergency actions
//   - TimeManager:    RTC DS3231 + NTP synchronization
//   - WaterManager:   TPA state machine (6 states)
//   - FertManager:    Daily dosing with NVS deduplication
//   - WebManager:     Embedded web dashboard + Serial command interface
// =============================================================================

#include "BootLog.h"
#include "Config.h"
#include "PumpLog.h"
#include "DisplayManager.h"
#include "FertManager.h"
#include "NotifyManager.h"
#include "SafetyWatchdog.h"
#include "TimeManager.h"
#include "WaterManager.h"
#include "WebManager.h"
#include <Arduino.h>
#include <LittleFS.h>
#include <esp_task_wdt.h>
#include <esp_wifi.h>
#include <ESPmDNS.h>
#include <driver/gpio.h>

// ============================================================================
// PRE-BOOT SAFETY: Force all output GPIOs LOW before Arduino setup()
// This eliminates the ~100-200ms window where pins float during ESP32 boot,
// which can briefly activate relays and trigger siphon effects.
// Runs automatically before app_main() via GCC constructor attribute.
// ============================================================================
static void __attribute__((constructor)) earlyPinInit() {
  const gpio_num_t pins[] = {
      (gpio_num_t)PIN_FERT1,    (gpio_num_t)PIN_FERT2,
      (gpio_num_t)PIN_FERT3,    (gpio_num_t)PIN_FERT4,
      (gpio_num_t)PIN_PRIME,    (gpio_num_t)PIN_DRAIN,
      (gpio_num_t)PIN_REFILL,   (gpio_num_t)PIN_SOLENOID,
      (gpio_num_t)PIN_CANISTER,
  };
  for (auto pin : pins) {
    gpio_reset_pin(pin);
    gpio_set_direction(pin, GPIO_MODE_OUTPUT);
    gpio_set_level(pin, 0); // LOW — relay OFF
  }
}

// ---- Global instances ----
SafetyWatchdog safety;
TimeManager timeMgr;
WaterManager waterMgr;
FertManager fertMgr;
WebManager webMgr;
DisplayManager displayMgr;
NotifyManager notifyMgr;

// ---- Scheduling state ----
bool fertDoneThisMinute = false; // Prevent re-triggering within same minute
uint8_t lastFertMinute = 255;
bool tpaDoneThisMinute = false;
uint8_t lastTPAMinute = 255;
bool emergencyNotified = false;   // Prevent repeated emergency notifications
bool tpaCompleteNotified = false; // Prevent repeated TPA complete notifications
// COMPLETE holds for many loop iterations, so persisting and propagating the
// calibration must happen once per cycle — not at 20 Hz against the flash.
bool calibrationSettled = false;
bool tpaErrorNotified = false;    // Prevent repeated TPA error notifications

// ---- WiFi Retry State ----
unsigned long lastWiFiRetryTime = 0;
const unsigned long WIFI_RETRY_INTERVAL_MS = 30000; // 30 seconds
bool wifiWasConnected = false; // Track WiFi state transitions for mDNS restoration

// Credentials are kept around after setup() so the recovery ladder can rebuild
// the station interface, which needs them again after a full radio restart.
String wifiSSID;
String wifiPass;

// How long the station has been down, and how many retries that took. Zero
// while connected.
unsigned long wifiDownSinceMs = 0;
uint16_t wifiRetryCount = 0;
bool apFallbackActive = false;

// Last disconnect reason code from the WiFi event handler, exposed on
// /api/status so the cause survives until someone looks.
volatile int lastWifiDisconnectReason = -1;

// How many times the station has dropped this run, and when the last one
// landed. A brownout that keeps arriving seconds after a reassociation says
// something a reason code on its own does not.
volatile uint16_t wifiDisconnectCount = 0;
volatile unsigned long lastWifiEventMs = 0;

// Offline for this long and the AP comes up, so the dashboard stays reachable
// even while the station keeps failing.
const unsigned long WIFI_AP_FALLBACK_MS = 120000UL; // 2 minutes
// Offline for this long and the board reboots, which is the only step that
// reliably clears a wedged radio or an exhausted socket pool.
const unsigned long WIFI_REBOOT_MS = 900000UL; // 15 minutes

// ---- Boot diagnostics (exposed via /api/status) ----
const char *bootResetReason = "UNKNOWN";
unsigned long bootTimeMs = 0; // millis() at end of setup

// =============================================================================
// SETUP
// =============================================================================
void setup() {
  // --- Step 1: Initialize all output pins LOW FIRST (safety critical) ---
  for (uint8_t i = 0; i < NUM_OUTPUT_PINS; i++) {
    pinMode(OUTPUT_PINS[i], OUTPUT);
  }
  allPumpsOff(PumpReason::BOOT_INIT);

  // --- Step 2: Serial ---
  Serial.begin(115200);
  delay(2000);

  // --- Step 2a: Log reset reason (diagnostic) ---
  // Recorded here rather than at the end of setup() on purpose: WiFi below can
  // hold the boot for 30 s, and a board resetting inside that window is
  // precisely the case the log exists to catch.
  const uint8_t resetReason = (uint8_t)esp_reset_reason();
  const char *resetStr = bootResetReasonName(resetReason);
  bootResetReason = resetStr;
  bootLogBegin(resetReason);

  Serial.println("\n==========================================");
  Serial.println("  AQUARIUM AUTOMATION - ESP32 Firmware");
  Serial.printf("  v%s - Pump Log + Safety\n", FIRMWARE_VERSION);
  Serial.printf("  Reset reason: %s\n", resetStr);
  Serial.println("==========================================\n");

  // --- Step 2b: I2C bus scan (diagnostic) ---
  Wire.begin(); // SDA=21, SCL=22
  Serial.println("[I2C] Scanning bus...");
  uint8_t devCount = 0;
  for (uint8_t addr = 1; addr < 127; addr++) {
    Wire.beginTransmission(addr);
    if (Wire.endTransmission() == 0) {
      Serial.printf("[I2C] Device found at 0x%02X", addr);
      if (addr == 0x3C || addr == 0x3D)
        Serial.print(" (SSD1306 OLED)");
      if (addr == 0x68)
        Serial.print(" (DS3231 RTC)");
      if (addr == 0x57)
        Serial.print(" (DS3231 EEPROM)");
      Serial.println();
      devCount++;
    }
  }
  Serial.printf("[I2C] Scan complete: %d device(s) found.\n", devCount);

  // --- Step 2c: OLED Display (early init for boot screen) ---
  displayMgr.initHardware();

  // --- Step 2c: Filesystem ---
  displayMgr.showBootStatus("LittleFS");
  if (!LittleFS.begin(true)) {
    Serial.println("[LittleFS] Mount Failed. Formatting...");
  } else {
    Serial.println("[LittleFS] Mounted successfully.");
  }

  // Load persisted pump log from flash
  pumpLogLoad();

  // --- Step 3: WiFi (must be before NTP/WebServer) ---
  displayMgr.showBootStatus("WiFi scan");
  Preferences wifiPref;
  wifiPref.begin("wifi", true); // true = readonly
  wifiSSID = wifiPref.getString("ssid", String(WIFI_SSID));
  wifiPass = wifiPref.getString("pass", String(WIFI_PASSWORD));
  wifiPref.end();
  String &savedSSID = wifiSSID;
  String &savedPass = wifiPass;

  Serial.printf("[WiFi] SSID: '%s'\n", savedSSID.c_str());
  Serial.printf("[WiFi] PASS: len=%d\n", savedPass.length());
  Serial.print("[WiFi] Connecting");

  // Add Event Listener to catch specific disconnect reasons
  WiFi.onEvent([](arduino_event_id_t event, arduino_event_info_t info) {
    if (event == ARDUINO_EVENT_WIFI_STA_DISCONNECTED) {
      lastWifiDisconnectReason = info.wifi_sta_disconnected.reason;
      if (wifiDisconnectCount < 0xFFFF) wifiDisconnectCount++;
      lastWifiEventMs = millis();

      // A radio the AP keeps refusing produces dozens of these a second, and
      // an unthrottled printf turns that into a serial flood that buries every
      // other line in the log. One summary per second says the same thing.
      static unsigned long lastLogMs = 0;
      static uint16_t suppressed = 0;
      const unsigned long nowMs = millis();
      if (nowMs - lastLogMs >= 1000) {
        if (suppressed) {
          Serial.printf("\n[WiFi Event] Disconnected! Reason Code: %d (+%u more)\n",
                        info.wifi_sta_disconnected.reason, (unsigned)suppressed);
        } else {
          Serial.printf("\n[WiFi Event] Disconnected! Reason Code: %d\n",
                        info.wifi_sta_disconnected.reason);
        }
        lastLogMs = nowMs;
        suppressed = 0;
      } else if (suppressed < 0xFFFF) {
        suppressed++;
      }
    }
  });

  WiFi.mode(WIFI_STA);         // Set STA mode first
  WiFi.disconnect(true, true); // Clean previous connections
  delay(500);

  // Advanced Router Compatibility Fixes (for TIM / Smart Routers)
  WiFi.setSleep(
      false); // Disable sleep for better compatibility with some routers
  WiFi.setAutoConnect(true);
  WiFi.setAutoReconnect(true);

  // Active Scan Workaround: Force the radio to wake up, populate the BSSID
  // cache, and extract the exact BSSID/Channel to avoid Reason 201 (NO AP FOUND
  // / Band Steering)
  Serial.print(" Scanning...");
  int n = WiFi.scanNetworks();
  delay(100);

  uint8_t targetBSSID[6] = {0};
  int32_t targetChannel = 0;
  bool bssidFound = false;

  for (int i = 0; i < n; ++i) {
    if (WiFi.SSID(i) == savedSSID) {
      memcpy(targetBSSID, WiFi.BSSID(i), 6);
      targetChannel = WiFi.channel(i);
      bssidFound = true;
      Serial.printf("\n[WiFi] Found Target BSSID: "
                    "%02X:%02X:%02X:%02X:%02X:%02X on Channel: %d\n",
                    targetBSSID[0], targetBSSID[1], targetBSSID[2],
                    targetBSSID[3], targetBSSID[4], targetBSSID[5],
                    targetChannel);
      break;
    }
  }

  // CRITICAL FIX: To prevent Reason 15 (4-way handshake timeout) on
  // TIM routers we need to set the WiFi config explicitly to disable Protected
  // Management Frames (PMF) because the ESP32 WPA3 implementation sometimes
  // fails to negotiate with modern mixed-mode routers.

  wifi_config_t wifi_config = {};
  strlcpy((char *)wifi_config.sta.ssid, savedSSID.c_str(),
          sizeof(wifi_config.sta.ssid));
  strlcpy((char *)wifi_config.sta.password, savedPass.c_str(),
          sizeof(wifi_config.sta.password));

  // Force WPA2 and Disable PMF completely to bypass the handshake hang
  wifi_config.sta.pmf_cfg.capable = false;
  wifi_config.sta.pmf_cfg.required = false;

  esp_wifi_set_config(WIFI_IF_STA, &wifi_config);

  // Re-attempt standard connection, locking to BSSID and Channel if found
  if (bssidFound) {
    WiFi.begin(savedSSID.c_str(), savedPass.c_str(), targetChannel, targetBSSID,
               true);
  } else {
    WiFi.begin(savedSSID.c_str(), savedPass.c_str());
  }

  {
    int attempts = 0;
    while (WiFi.status() != WL_CONNECTED &&
           attempts < 60) { // Incremented timeout (Reason 39)
      delay(500);
      Serial.print(".");
      attempts++;
    }
  }
  if (WiFi.status() == WL_CONNECTED) {
    Serial.println(" OK!");
    Serial.print("[WiFi] IP: ");
    Serial.println(WiFi.localIP());
    char ipBuf[22];
    snprintf(ipBuf, sizeof(ipBuf), "IP: %s", WiFi.localIP().toString().c_str());
    displayMgr.showBootStatus(ipBuf);

    // Start mDNS Responder
    if (MDNS.begin("iara")) {
      Serial.println("[mDNS] Responder started at http://iara.local");
      MDNS.addService("http", "tcp", 80);
    } else {
      Serial.println("[mDNS] Error setting up mDNS responder!");
    }
    wifiWasConnected = true;
  } else {
    Serial.println(" FAILED!");
    Serial.print("[WiFi] Error Code: ");
    switch (WiFi.status()) {
    case WL_NO_SHIELD:
      Serial.println("WL_NO_SHIELD");
      break;
    case WL_IDLE_STATUS:
      Serial.println("WL_IDLE_STATUS");
      break;
    case WL_NO_SSID_AVAIL:
      Serial.println("WL_NO_SSID_AVAIL");
      break;
    case WL_SCAN_COMPLETED:
      Serial.println("WL_SCAN_COMPLETED");
      break;
    case WL_CONNECT_FAILED:
      Serial.println("WL_CONNECT_FAILED");
      break;
    case WL_CONNECTION_LOST:
      Serial.println("WL_CONNECTION_LOST");
      break;
    case WL_DISCONNECTED:
      Serial.println("WL_DISCONNECTED");
      break;
    default:
      Serial.printf("UNKNOWN (%d)\n", WiFi.status());
      break;
    }

    Serial.println("[WiFi] Starting AP mode fallback");
    WiFi.mode(WIFI_AP_STA); // AP + keep trying STA in background
    WiFi.softAP(AP_SSID, AP_PASSWORD);
    apFallbackActive = true;
    Serial.printf("[WiFi] AP started: SSID='%s' PASS='%s'\n", AP_SSID,
                  AP_PASSWORD);
    Serial.print("[WiFi] AP IP: ");
    Serial.println(WiFi.softAPIP());
    displayMgr.showBootStatus("WiFi: AP Mode");
    
    // Start mDNS Responder for AP mode
    if (MDNS.begin("iara")) {
      Serial.println("[mDNS] Responder started at http://iara.local (AP Mode)");
      MDNS.addService("http", "tcp", 80);
    }
    // Removed immediate WiFi.begin() because it disrupts the SoftAP network.
  }

  // --- Step 4: Safety Watchdog (sensors) ---
  displayMgr.showBootStatus("Sensors");
  safety.begin();

  // --- Step 5: Time Manager (RTC + NTP — needs WiFi) ---
  displayMgr.showBootStatus("RTC + NTP");
  timeMgr.begin();
  pumpLogInit([]() -> String { return timeMgr.getFormattedTime(); });

  // --- Step 5: Fertilizer Manager (NVS state) ---
  fertMgr.begin();

  // --- Step 6: Water Manager (TPA state machine) ---
  waterMgr.begin(&safety, &fertMgr);

  // Load calibrated pump flow rates from NVS
  waterMgr.loadCalibration();

  // --- Step 7: Web Dashboard + Serial UI ---
  displayMgr.showBootStatus("Web server");
  webMgr.begin(&timeMgr, &waterMgr, &fertMgr, &safety, &notifyMgr);

  // --- Step 7b: OLED Display (full init with managers) ---
  displayMgr.begin(&timeMgr, &waterMgr, &fertMgr, &safety, &webMgr, &notifyMgr);
  displayMgr.showBootStatus("System ready!");
  delay(1000); // pause to show final boot log

  // --- Step 8: Canister filter ON by default ---
  pumpOff(PIN_CANISTER, PumpReason::BOOT_INIT); // SSR: LOW = relay ON
  Serial.println("[Main] Canister filter ON (default).\n");

  // --- Step 9: Notifications ---
  notifyMgr.begin();
  notifyMgr.setLanguage(webMgr.getLanguage());

  // --- Step 10: Disable Task Watchdog ---
  // NOTE: the original justification was that ultrasonic pulseIn() blocked the
  // loop for ~300 ms. That driver is gone — the A02YYUW streams over UART — and
  // fertiliser dosing no longer blocks either, so the loop is now short. The
  // task WDT is a genuine backstop against a hung loop, which SafetyWatchdog
  // cannot catch because it runs *from* that loop. Re-enabling it is the right
  // move, but it changes reboot behaviour mid-cycle and wants to be verified on
  // the bench rather than flipped blind.
  disableLoopWDT();
  disableCore0WDT();
  Serial.println("[WDT] Task watchdog disabled (SafetyWatchdog active).");

  Serial.println("[Main] === System Ready ===\n");
}
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

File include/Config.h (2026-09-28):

#pragma once

#include <Arduino.h>

// ============================================================================
// FIRMWARE VERSION
// ============================================================================
#ifndef FIRMWARE_VERSION
#define FIRMWARE_VERSION "3.2.1"
#endif

// ============================================================================
// HARDWARE PIN MAPPING
// ============================================================================

// --- MOSFET Channels (Active HIGH) ---
// Fertilizers CH1-CH4
constexpr uint8_t PIN_FERT1 = 13; // CH1 - Fertilizer 1
constexpr uint8_t PIN_FERT2 = 12; // CH2 - Fertilizer 2
constexpr uint8_t PIN_FERT3 = 14; // CH3 - Fertilizer 3
constexpr uint8_t PIN_FERT4 = 27; // CH4 - Fertilizer 4
constexpr uint8_t PIN_PRIME = 26; // CH5 - Prime (dechlorinator)

// TPA Actuators
constexpr uint8_t PIN_DRAIN = 25;    // CH6 - Drain pump
constexpr uint8_t PIN_REFILL = 33;   // CH7 - Refill pump (recalque)
constexpr uint8_t PIN_SOLENOID = 32; // CH8 - Solenoid valve

// Filtration
// GPIO2 is a strapping pin the ROM samples at boot, with the on-board LED
// hanging off it on most dev boards, so the SSR's gate gets driven for a
// moment before the firmware runs. Kept anyway: the relay is one wire into the
// gap the display's block leaves open, and the pre-boot GPIO forcing in
// main.cpp already holds it at the level that keeps the filter off.
constexpr uint8_t PIN_CANISTER = 2; // Relay SSR for canister filter

// --- Sensors ---
// The A02YYUW's control lead is wired here. Nothing writes to Serial2 — the
// sensor streams unprompted — but keeping it as the UART TX pin holds the line
// at the idle-high level the sensor needs to stay in continuous mode.
constexpr uint8_t PIN_US_TX = 18; // Ultrasonic A02 control lead (idle high)
constexpr uint8_t PIN_US_RX = 34; // Ultrasonic A02 UART RX (from TX on sensor)
// NOTE: GPIO4 was the XKC-Y25 capacitive max-level sensor. That sensor was
// never installed and has been dropped: max-level protection is now a physical
// reed switch wired in series with the refill pump's +12 V line, which cuts the
// pump independently of the firmware. Being on the power side rather than on
// the gate signal, it also covers the MOSFET failing shorted. GPIO4 now carries
// the display's SDA line.
constexpr uint8_t PIN_FLOAT =
    19; // Horizontal float switch reservoir (Moved from 5 to 19 for stability)
// --- TFT Display (ST7735, SPI) ---
// Board pins: VCC, GND, CS, RESET, A0, SDA, SCK, LED
//
// Every line the module needs now sits in one unbroken run at the bottom of the
// right-hand header — 3V3, GND, D15, D4, D16, D17 — so the display leaves the
// board as a single ribbon instead of four wires crossing it. GPIO4 was free
// (the XKC-Y25 that owned it was never installed) and GPIO2, the one gap in
// that run, keeps the canister relay — one wire into the middle of the block.
// GPIO23, which SDA vacated, is now the free pin.
//
// Software SPI (see the Adafruit_ST7735 constructor in DisplayManager), so
// these are ordinary GPIOs with no VSPI/HSPI constraint.
constexpr uint8_t PIN_TFT_CS = 15;   // CS   — Chip Select
constexpr uint8_t PIN_TFT_DC = 17;   // A0   — Data/Command
constexpr uint8_t PIN_TFT_MOSI = 4;  // SDA  — SPI Data
constexpr uint8_t PIN_TFT_SCK = 16;  // SCK  — SPI Clock
constexpr int8_t PIN_TFT_RST = -1;   // RESET — Tied to ESP32 EN

// --- Navigation Button ---
// Panel button. GPIO5 is a strapping pin, so it must not be held down through
// power-on; a momentary press at any other time is harmless.
constexpr uint8_t PIN_BTN = 5; // Panel button (INPUT_PULLUP, active LOW)

// --- Display ---
// Blank the TFT after this long without a button press. Only clears pixels —
// the backlight is hardwired to 3.3V on this module and cannot be switched.
constexpr unsigned long DISPLAY_TIMEOUT_MS = 30UL * 1000; // 30s auto-off

// --- I2C (DS3231 RTC) ---
// Using ESP32 default I2C: SDA=21, SCL=22

// ============================================================================
// ALL OUTPUT PINS (for batch initialization)
// ============================================================================
constexpr uint8_t OUTPUT_PINS[] = {PIN_FERT1,  PIN_FERT2,    PIN_FERT3,
                                   PIN_FERT4,  PIN_PRIME,    PIN_DRAIN,
                                   PIN_REFILL, PIN_SOLENOID, PIN_CANISTER};
constexpr uint8_t NUM_OUTPUT_PINS =
    sizeof(OUTPUT_PINS) / sizeof(OUTPUT_PINS[0]);

// Fertilizer pin array for indexed access
constexpr uint8_t FERT_PINS[] = {PIN_FERT1, PIN_FERT2, PIN_FERT3, PIN_FERT4};
constexpr uint8_t NUM_FERTS = 4;

// ============================================================================
// TIMING & SAFETY CONSTANTS
// ============================================================================
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

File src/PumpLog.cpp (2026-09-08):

#include "PumpLog.h"

#ifndef UNIT_TEST
#include <LittleFS.h>
#endif

// ============================================================================
// INTERNAL STATE
// ============================================================================

static TimeFormatCallback _timeCb = nullptr;

// Actuators believed to be on, bit N = OUTPUT_PINS[N].
static uint16_t _activeMask = 0;

// Ring buffer
static PumpLogEntry _logBuffer[PUMP_LOG_MAX];
static uint8_t _logHead = 0;  // Next write position
static uint8_t _logCount = 0; // Current number of entries

// Persistence state
static bool _dirty = false;
static unsigned long _lastFlushMs = 0;

#ifndef UNIT_TEST

static const char *LOG_FILE = "/pumplog.bin";

// File header magic to detect valid log files
static const uint32_t LOG_MAGIC = 0x504C4F47; // "PLOG"

struct PumpLogHeader {
  uint32_t magic;
  uint8_t count;
  uint8_t head;
  uint8_t version; // for future format changes
  uint8_t _pad;
};

// ============================================================================
// INITIALIZATION
// ============================================================================

void pumpLogInit(TimeFormatCallback cb) { _timeCb = cb; }

// ============================================================================
// PERSISTENCE — LittleFS
// ============================================================================

void pumpLogLoad() {
  File f = LittleFS.open(LOG_FILE, "r");
  if (!f) {
    Serial.println("[PumpLog] No saved log file found. Starting fresh.");
    return;
  }

  PumpLogHeader hdr;
  if (f.read((uint8_t *)&hdr, sizeof(hdr)) != sizeof(hdr) ||
      hdr.magic != LOG_MAGIC || hdr.count > PUMP_LOG_MAX) {
    Serial.println("[PumpLog] Invalid log file. Starting fresh.");
    f.close();
    return;
  }

  size_t dataSize = PUMP_LOG_MAX * sizeof(PumpLogEntry);
  size_t readSize = f.read((uint8_t *)_logBuffer, dataSize);
  f.close();

  if (readSize != dataSize) {
    Serial.println("[PumpLog] Corrupt log file. Starting fresh.");
    memset(_logBuffer, 0, dataSize);
    _logCount = 0;
    _logHead = 0;
    return;
  }

  _logCount = hdr.count;
  _logHead = hdr.head;
  Serial.printf("[PumpLog] Loaded %d events from flash.\n", _logCount);
}

// LittleFS writes were deadlocking the loop against the async web server's
// task, so persistence is off: the pump log lives in RAM and does not survive a
// reboot. This is a named constant rather than an early `return;` above a full
// function body, because that reads as working code to anyone scanning the file
// — and the whole point of a pump log is being able to trust it after the event
// you wanted to investigate.
static constexpr bool PUMP_LOG_PERSIST = false;

void pumpLogFlush() {
  if (!PUMP_LOG_PERSIST) return;
  if (!_dirty) return;

  unsigned long now = millis();
  if (now - _lastFlushMs < PUMP_LOG_FLUSH_INTERVAL_MS) return;

  File f = LittleFS.open(LOG_FILE, "w");
  if (!f) {
    Serial.println("[PumpLog] Failed to open log file for writing!");
    return;
  }

  PumpLogHeader hdr;
  hdr.magic = LOG_MAGIC;
  hdr.count = _logCount;
  hdr.head = _logHead;
  hdr.version = 1;
  hdr._pad = 0;

  f.write((uint8_t *)&hdr, sizeof(hdr));
  f.write((uint8_t *)_logBuffer, PUMP_LOG_MAX * sizeof(PumpLogEntry));
  f.close();

  _dirty = false;
  _lastFlushMs = now;
}

#else // UNIT_TEST stubs

void pumpLogInit(TimeFormatCallback cb) { _timeCb = cb; }
void pumpLogLoad() {}
void pumpLogFlush() {}

#endif // UNIT_TEST

// ============================================================================
// NAME LOOKUPS
// ============================================================================

const char *pinName(uint8_t pin) {
  if (pin == PIN_FERT1) return "FERT1";
  if (pin == PIN_FERT2) return "FERT2";
  if (pin == PIN_FERT3) return "FERT3";
  if (pin == PIN_FERT4) return "FERT4";
  if (pin == PIN_PRIME) return "PRIME";
  if (pin == PIN_DRAIN) return "DRAIN";
  if (pin == PIN_REFILL) return "REFILL";
  if (pin == PIN_SOLENOID) return "SOLENOID";
  if (pin == PIN_CANISTER) return "CANISTER";
  return "UNKNOWN";
}

const char *reasonName(PumpReason r) {
  switch (r) {
  case PumpReason::TPA_DRAINING:       return "TPA_DRAINING";
  case PumpReason::TPA_REFILLING:      return "TPA_REFILLING";
  case PumpReason::TPA_CANISTER:       return "TPA_CANISTER";
  case PumpReason::TPA_SOLENOID:       return "TPA_SOLENOID";
  case PumpReason::TPA_PRIME:          return "TPA_PRIME";
  case PumpReason::TPA_TARGET_REACHED: return "TPA_TARGET_REACHED";
  case PumpReason::MANUAL_PUMP:        return "MANUAL_PUMP";
  case PumpReason::MANUAL_SOLENOID:    return "MANUAL_SOLENOID";
  case PumpReason::CALIBRATION:        return "CALIBRATION";
  case PumpReason::EMERGENCY_DRAIN:    return "EMERGENCY_DRAIN";
  case PumpReason::EMERGENCY_SHUTDOWN: return "EMERGENCY_SHUTDOWN";
  case PumpReason::SAFETY_STOP:        return "SAFETY_STOP";
  case PumpReason::ERROR_STOP:         return "ERROR_STOP";
  case PumpReason::ABORT:              return "ABORT";
  case PumpReason::BOOT_INIT:          return "BOOT_INIT";
  case PumpReason::FERT_SCHEDULED:     return "FERT_SCHEDULED";
  case PumpReason::FERT_MANUAL:        return "FERT_MANUAL";
  default:                             return "UNKNOWN";
  }
}

// ============================================================================
// RING BUFFER
// ============================================================================

static void _addEntry(uint8_t pin, bool state, PumpReason reason) {
  // Every path that changes an actuator lands here, which makes this the one
  // place the mask can be kept honest.
  for (uint8_t i = 0; i < NUM_OUTPUT_PINS; i++) {
    if (OUTPUT_PINS[i] != pin) continue;
    if (state) _activeMask |= (uint16_t)(1u << i);
    else _activeMask &= (uint16_t)~(1u << i);
    break;
  }

  PumpLogEntry &entry = _logBuffer[_logHead];

  // Timestamp
  if (_timeCb) {
    String ts = _timeCb();
    strncpy(entry.timestamp, ts.c_str(), sizeof(entry.timestamp) - 1);
    entry.timestamp[sizeof(entry.timestamp) - 1] = '\0';
  } else {
    snprintf(entry.timestamp, sizeof(entry.timestamp), "%lums", millis());
  }

  entry.pin = pin;
  entry.state = state;
  entry.reason = reason;
  entry._pad = 0;

  _logHead = (_logHead + 1) % PUMP_LOG_MAX;
  if (_logCount < PUMP_LOG_MAX) {
    _logCount++;
  }
  _dirty = true;
}

PumpLogEntry pumpLogLast() {
  if (_logCount == 0)
    return PumpLogEntry{};
  // _logHead is the next write position, so the newest entry is behind it.
  return _logBuffer[(_logHead + PUMP_LOG_MAX - 1) % PUMP_LOG_MAX];
}

uint8_t pumpLogCount() { return _logCount; }

uint16_t pumpLogActiveMask() { return _activeMask; }
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

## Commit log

2026-03-02 docs: update sensor to capacitive XKC-Y25-NPN and add Buy Me a Coffee
    - Replace optical sensor with capacitive non-contact sensor (XKC-Y25-NPN) in BOM.md
    - Add capacitive sensor wiring diagram to HARDWARE.md
    - Update mermaid diagrams in both READMEs
    - Update Config.h sensor comment
    - Add Buy Me a Coffee section to both READMEs
    [Config.h]
2026-03-02 feat: add ESP32 hardware watchdog + non-blocking delays
    Safety improvements:
    - Enable ESP32 Task WDT (10s timeout, auto-reboot on freeze)
    - Replace blocking delay(3000) in _handleCanisterOff() with millis()
    - Replace blocking delay(2000) in _handleDosingPrime() with millis()
    - Add delay(10) CPU throttle (~100Hz loop) to prevent overheating
    - Add _waitUntilMs and _isWaiting() for non-blocking state waits
    Documentation:
    - Add Safety & Reliability section to README.md and README.pt-BR.md
    - Document software protections (WDT, timeouts, NVS dedup, CPU throttle)
    - Document hardware recommendations (overflow float, flyback, capacitors)
    Tests:
    - Update test_water_manager helpers for non-blocking C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
    [Arduino.cpp, Arduino.h, WaterManager.cpp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]
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2026-03-02 feat: canister safe level as percentage + mandatory TPA config
    - Replace fixed cm canister safe level with configurable percentage
    - Add _canisterSafePct to WebManager: JSON API, /api/schedule, NVS
    - Add canisterSafePct > 0 to isTpaConfigReady() — blocks TPA if not set
    - Compute cm from percentage in main.cpp: effH × (100 - pct) / 100
    - Default 0% = must be explicitly configured before TPA can start
    - Mandatory TPA config now requires: aquarium dims, reservoir volume,
    TPA percentage, AND canister safe percentage
    [WebManager.cpp, WebManager.h, main.cpp]
2026-03-03 feat: show water level as percentage in error notifications
    - Add _aqEffectiveHeightCm to WaterManager for cm→% conversion
    - Error push now shows: 'Drain timeout | Canister: OFF (nivel 45%, min: 60%)'
    - Convert both current level and safe threshold to % using effH
    [WaterManager.cpp, WaterManager.h, main.cpp]
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2026-03-03 feat(3d): revise electronics enclosure for 199×98×42mm PSU
    Major layout revision for the electronics enclosure:
    Enclosure:
    - Increased box_depth from 200mm to 220mm for larger PSU
    - Increased box_height from 60mm to 62mm (PSU 42mm + clearance)
    - PSU centered (offset_x=0) due to 199mm width
    Module repositioning (avoiding PSU overlap):
    - MOSFET 8CH: (-70, 48), rotated 90°
    - ESP32: (40, 45)
    - LM2596: (-20, 55), rotated 90°
    - ULTRA sensor: (40, 85)
    - SSR: (90, 30), rotated 90°
    - RTC DS3231: (40, 8)
    Panel changes:
    - Back panel: cleared (PSU occupies full width)
    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
    [electronics_enclosure.scad]
2026-03-03 fix(3d): corrigir standoffs flutuando em relação ao fundo
    O módulo module_standoffs tinha um offset Z=wall hardcoded
    internamente, causando standoffs flutuantes na test_plate
    (offset duplicado: plate_h + wall) e sem overlap na base.
    - Removido offset wall de dentro de module_standoffs (agora Z=0)
    - Callers passam Z=wall-0.5 (base) e Z=plate_h-0.5 (test_plate)
    - O -0.5mm garante penetração no fundo para geometria sólida
    [electronics_enclosure.scad]
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2026-03-03 fix(3d): correct finger-joint alignment on laser-cut enclosure
    - Fix lateral finger-joint offsets on bottom panel (mat_t shift)
    - Fix front/back panel lateral tab positions for proper mating
    - Add vertical finger-joint slots to left/right side panels
    (previously missing, sides had no interlock with front/back)
    - Export updated DXF for laser cutting
    [electronics_enclosure_laser.dxf, electronics_enclosure_laser.scad]
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2026-03-04 fix(frontend): reset FertCard state on channel switch
    Add key={openChannelIndex} to FertCard component so React remounts
    it when switching channels. This resets all local state (name, doses,
    PWM, calibMl, resetVol) to the selected channel's data.
    Also fix i18n: NEXT TPA → NEXT WC for EN/JA locale on TFT display.
    [DisplayManager.cpp]
2026-03-05 fix(display): partial redraw to eliminate flicker
    - Full fillScreen only on page switch (every 5s)
    - Schedule page: partial redraw of clock area only (every 1s)
    via fillRect on 160x26px region instead of full screen clear
    - Other pages: static between page switches (no flicker)
    [DisplayManager.cpp]
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2026-03-05 feat(3d): update enclosure cutout from OLED to ST7735 TFT 1.8"
    Replace OLED SSD1306 0.96" dimensions with ST7735 1.8" TFT:
    - Screen: 25.5×14mm → 35×28mm
    - PCB: 27×30mm → 56×34mm
    - Mount holes: 23.5mm → 52×30mm spacing
    - Updated both 3D print and laser cut files
    - Renamed all oled_* params to tft_*
    [electronics_enclosure_3d.scad, electronics_enclosure_laser.scad]
2026-03-05 fix(display): reset textSize in header level bar to prevent font leak
    The schedule page clock sets textSize(3), which leaked into
    _drawHeaderLevelBar() on the next 1s redraw, causing the
    percentage text to render at 3× size.
    [DisplayManager.cpp]
2026-03-05 feat(laser): add lid + button hole + optimized 2-column layout
    - Add btn_panel_d (12mm) parameter for panel push button
    - Add button hole to front panel (base_2d_front) next to RJ45 sensors
    - Remove rubber feet recesses from bottom panel (not needed for laser)
    - Add button hole to lid (lid_2d) next to TFT opening
    - Fix spacing variable scope in all_2d() (was undef, causing overlap)
    - Optimize all_2d() layout: 2 columns for minimum sheet usage
    Col 1: Bottom + Front + Back (250mm panels)
    Col 2: Lid + Left + Right (220mm panels)
    Sheet size: ~540mm × 360mm (fits 600×400 standard)
    [electronics_enclosure_laser.dxf, electronics_enclosure_laser.scad]
2026-05-27 feat(3d): chihiros-shades com comprimento configurável e ajustes de encaixe
    - Comprimento da peça agora é configurável via variável (default: 200mm)
    - Base alargada 1mm na diagonal (preserva ângulo de 45°)
    - Rampa engrossada 1.5mm na diagonal oposta
    - Clipe rosa encurtado 1.5mm (base sobe, topo fixo)
    - Removidas bolinhas de debug do modo de impressão
    [chihiros-shades.scad, chihiros-shades.stl, dosing_pump_support_laser.dxf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]
2026-05-28 fix(3d): reduz diagonal base de 1.0mm para 0.75mm + limpeza de formatação
    [chihiros-shades.scad, chihiros-shades.stl]
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2026-06-07 fix(web): disable cache control for static files to avoid aggressive mobile caching
    [WebManager.cpp]
2026-06-08 feat: add canister toggle, fix manual pump cancel, fix TFT level percent
    [DisplayManager.cpp, WebManager.cpp, WebManager.h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]
2026-06-08 fix(ui/core): resolve canister 500 error, correct live display pct, disable screen timeout, restore TPA cancel button
    [DisplayManager.cpp]
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2026-06-09 feat(3d_models): reconstruct Chihiros light support base geometry, fix non-manifold artifacts, and add mounting holes
    [chihiros_support_final.stl, chihiros_support_solid.scad, chihiros_support_solid.stl]
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2026-06-10 fix: sync WebManager flow rates from WaterManager on boot to prevent UI showing uncalibrated state
    [WebManager.cpp]
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2026-06-13 fix: pre-boot GPIO safety — force all relay pins LOW before setup()
    Uses GCC __attribute__((constructor)) to call earlyPinInit() before
    Arduino's app_main(). This eliminates the ~100-200ms window where
    GPIO pins float during ESP32 boot, which can briefly activate relays
    and trigger siphon effects in the drain line.
    Root cause of overnight water loss: brief GPIO float → drain relay ON →
    siphon formed → water continued draining after relay turned OFF.
    [main.cpp]
2026-06-13 feat: boot diagnostics — log reset reason + expose via /api/status
    - esp_reset_reason() decoded at boot: POWER_ON, BROWNOUT, PANIC, WATCHDOG, etc.
    - New JSON fields: resetReason, uptimeMs in /api/status
    - Enables remote diagnosis of unexpected reboots without USB serial
    - Version bumped to v3.1.0
    [WebManager.cpp, main.cpp]
2026-06-13 feat: persistent pump log — survives reboots via LittleFS
    - Ring buffer now persisted to /pumplog.bin on flash (binary format)
    - pumpLogLoad(): reads from LittleFS on boot, restores previous log
    - pumpLogFlush(): debounced write every 10s (flash wear protection)
    - Magic header (PLOG) + version field for format validation
    - UNIT_TEST guard: stubs for native test environment
    - Updated i18n to reflect persistence
    - 109/109 tests passing
    [PumpLog.cpp, main.cpp]
2026-06-14 v3.2.0: fix prime toggle, float debounce, reservoir calibration
    Bugfixes:
    - Wire setPrimeEnabled() from WebManager to WaterManager (was never called)
    - Add float sensor debounce (5 consecutive reads) to prevent false triggers
    - Add safety timeout to manual reservoir fill
    Features:
    - New CALIBRATING_RESERVOIR state for solenoid fill calibration
    - POST /api/tpa/calibrate-reservoir endpoint
    - Calibrated fill time saved to NVS and used as smart timeout (1.5x)
    - solenoidFillTimeSec and reservoirCalibrated exposed in /api/status
    - 109/109 passing with DRY simulateFloatFull() helper
    - All debounce-aware test updates
    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
    [Config.h, WaterManager.cpp, WaterManager.h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]
2026-06-14 v3.2.1: add config load/save/sync logging
    - Log all NVS values on _loadParams() (namespace: aqua)
    - Log key values on _saveParams()
    - Log WebManager <-> WaterManager sync at boot
    - Helps debug calibration data loss across reboots
    [WebManager.cpp]
2026-06-17 fix(tpa): fix pumpcal NVS sync, restore manual TPA UI buttons, and general module improvements
    - Fix WaterManager / WebManager preference synchronization for drain/refill calibration when upgrading firmware
    - Restore 'Start TPA' and 'Abort TPA' manual buttons to the React Dashboard (HomeTab)
    - Improve TimeManager, FertManager, and WaterManager architecture
    [FertManager.cpp, TimeManager.cpp, WaterManager.cpp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]
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2026-06-29 v3.2.2: fix GPIO 5 2.5V float switch interference by using INPUT_PULLDOWN and 3.3V
    [SafetyWatchdog.cpp]
2026-06-29 fix: resolve native environment unit test failures and restore TPA state transitions
    - test/mocks/Arduino.h: Add missing INPUT_PULLDOWN mock definition
    - test/mocks/Preferences.h: Add missing remove(), putBytes(), getBytes() methods required by FertManager
    - src/WaterManager.cpp: Fix TPA state transition bug introduced in 99b4103 where _primeEnabled caused skipping of FILLING_RESERVOIR and incorrect state looping to CANISTER_OFF
    - test/test_notify_manager: Update deprecated setPrivateKey to setTopic to match latest NotifyManager API
    - test/test_water_manager & test_drain_pump_safety: Fix float switch HIGH/LOW logic inversion, mock state leakages across tests, and TIMEOUT_DRAIN_MS constants t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
    [Arduino.h, WaterManager.cpp, test_drain_pump_safety.cpp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]
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2026-07-05 fix: resolve emergency deadlock and add clearEmergency toggle
    - Config.h: migrate PIN_FLOAT from D5 (damaged) to GPIO 19
    - SafetyWatchdog: move _updateEmergencyDrain() before sensor check
    so emergency timeout runs even when sensors are disconnected
    - SafetyWatchdog: add clearEmergency() to reset emergency state
    - WebManager: emergency_stop button now toggles (clear if active,
    activate if inactive), also resets TPA state to IDLE on clear
    - PumpLog: disable LittleFS flush temporarily to prevent deadlock
    when filesystem is corrupted after full erase
    [Config.h, PumpLog.cpp, SafetyWatchdog.cpp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]
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2026-08-25 fix: close safety gaps, remove dead code and move credentials out of the repo
    Safety
    - Re-enable emergencyDrain(). The overflow check counted its 10 consecutive
    readings, printed "CONFIRMED OVERFLOW" and then did nothing: the call had
    been commented out in 1469a5b, a commit about pump progress and mDNS.
    - DRAINING and REFILLING now abort when the ultrasonic goes stale.
    readUltrasonic() returns the last good value when no frame arrives, so the
    setpoint was being compared against a frozen number while a pump ran.
    - Manual pump goals are tracked by the sensor, like the automatic states, with
    flow x time kept as a backstop. startManualPump() refuses a goal it cannot
    measure — with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
    [Config.h, DisplayManager.cpp, NotifyManager.cpp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]
2026-08-25 fix: derive overflow threshold from calibration, not from placeholder config
    Flashing a fresh board put it straight into a false emergency: the drain
    opened on a healthy tank and, because main.cpp skips everything while the
    emergency flag is set, no pump or solenoid would respond afterwards.
    Root cause: _sensorFullDistanceMm defaulted to 100 mm on empty NVS, so
    getOverflowThresholdCm() returned a live 10 cm threshold on a board that had
    never been calibrated. Any sensor mounted closer than that read as a flood.
    The call was harmless while emergencyDrain() sat commented out; re-enabling it
    in the previous commit turned a latent misconfiguration into an active one.
    - The default is now 0, me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
    [Config.h, SafetyWatchdog.cpp, SafetyWatchdog.h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]
2026-08-25 fix: put the panel button on GPIO5, where it is actually wired
    The previous commit freed GPIO18 — reserved as the ultrasonic UART TX pin but
    never written to — and reassigned it to the panel navigation button. That was
    wrong: GPIO18 physically carries the A02YYUW's control lead, and the button is
    wired to GPIO5.
    With GPIO18 configured as an INPUT_PULLUP button, any low excursion on the
    sensor's control line would read as a button press. A long press opens the
    display menu, from which a water change can be started, so a phantom press
    could begin a TPA on its own.
    PIN_US_TX is restored and passed to Serial2.begin() again. Nothing writes to
    Serial2 — the sensor streams unprompted — bu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
    [Config.h, SafetyWatchdog.cpp]
2026-08-25 feat: one-shot flow calibration, and make a manual run's measurement stick
    Calibrating a pump was impossible in practice. Three things were in the way:
    - WaterManager measured the flow, but isTpaConfigReady() and /api/status read
    WebManager's copy, and the two were only reconciled inside WebManager::begin().
    A manual run's measurement was therefore invisible until the next boot.
    - stopManual() captured the flow but never persisted it, so that reboot erased
    it anyway. saveCalibration() only ran at the end of a full TPA — which cannot
    start without the flow rates it would have produced.
    - Getting a usable number meant eyeballing the clock while holding the pump on.
    The begin() reco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
    [Config.h, SafetyWatchdog.cpp, SafetyWatchdog.h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]
2026-08-25 fix: set aquarium geometry outside triggerTPA, so calibration can run at all
    Flow calibration could never succeed, and the reason predates the calibrate
    button: WaterManager::_litersPerCm was only ever assigned inside triggerTPA().
    Outside a running water change it stayed zero, and every path that converts a
    level change into litres checks it first — startPumpCalibration() refuses,
    _captureDrainCalibration() skips, _calcFlowRate() returns zero.
    That closed a loop with no way in: calibrating needs litersPerCm, litersPerCm
    is set when a TPA starts, and a TPA cannot start without calibrated flow rates.
    The geometry (litersPerCm, effective height, canister safe level) is now pushed
    into Wate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
    [WebManager.cpp, WebManager.h, main.cpp]
2026-08-25 fix: fill the reservoir before draining, and reject noise-sized calibrations
    Two problems the first real water change exposed.
    The cycle drained the aquarium before filling the reservoir, so a failure at
    the reservoir step happened with the tank already low. That is exactly what
    occurred: a loose contact left the solenoid inert, the fill never completed,
    and the refill then had less water available than had been drained — the tank
    was left short and had to be topped up by hand.
    The order is now FILLING_RESERVOIR -> DOSING_PRIME -> CANISTER_OFF -> DRAINING
    -> REFILLING -> CANISTER_ON. Everything that can fail at the reservoir now
    fails while the aquarium is still full and the canister sti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
    [Config.h, WaterManager.cpp, test_drain_pump_safety.cpp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]
2026-08-25 fix: never restore the canister below its safe level, and stop it while measuring
    The safe-level check existed only inside _error(). The one-hour auto-restore in
    main.cpp switched the filter back on with no level check at all, so a drained
    aquarium left alone for an hour would start the canister with its intake above
    the water — precisely what canisterSafePct is configured to prevent.
    The rule now lives in WaterManager::restoreCanisterIfSafe() and every path that
    brings the filter back goes through it: the error path, the one-hour restore,
    and the end of a manual run. When the level is too low the filter stays off and
    says why, and the hourly check simply comes round again later.
    Manual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
    [WaterManager.cpp, WaterManager.h, main.cpp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]
2026-08-25 fix: confirm the refill setpoint on a settled surface before ending the cycle
    The first real water change reported TPA_TARGET_REACHED and finished with the
    aquarium visibly short — it had to be topped up by hand. The stop was already
    sensor-based, not derived from the flow rate, so the sensor genuinely believed
    the level was restored.
    Two things make that reading optimistic, and both act in the same direction.
    Water pouring in near the sensor lifts and foams the surface directly beneath
    it, so the echo returns from something higher than the bulk level. And the
    reference the reading is compared against — _refillTargetCm — is captured in
    triggerTPA() while the canister is still running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
    [Config.h, WaterManager.cpp, WaterManager.h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]
2026-08-25 feat: calibrate both pumps in one pass, so neither needs headroom of its own
    Calibrating a pump on its own runs into a wall on a settled aquarium. The
    refill needs room above the current level to add water, but the level sits at
    the calibrated 100% mark and the overflow guard trips 3% above it. The drain
    has the mirror problem in reverse. Neither can be measured without first
    disturbing the tank by hand.
    startPairedCalibration() runs them back to back: drain until the level has
    moved CALIBRATION_MIN_DELTA_PCT, then refill the same amount. The drain leg
    creates exactly the headroom the refill leg needs, both rates are measured over
    the same level change, and the tank ends where it started. T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
    [WaterManager.cpp, WaterManager.h, WebManager.cpp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]
2026-08-25 fix: let the measured level end a manual run, not the estimated flow
    A manual run stopped on whichever came first: the ultrasonic reaching the
    target level, or elapsed time multiplied by the calibrated flow rate reaching
    the goal in litres. With the refill rate mis-calibrated at 19 L/min against a
    real 2-3 L/min, the estimate always won — a 10% goal ended after twenty seconds
    having moved a fraction of that, and reported success.
    The flow estimate was only ever meant to cover a silent sensor, so it now only
    applies when there is no sensor to trust. When a target level was computed and
    the ultrasonic is reporting, the level decides alone: measured beats estimated.
    The dynamic timeout had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
    [WaterManager.cpp, test_drain_pump_safety.cpp]
2026-08-25 fix: report pump progress from the measured level, never from the flow estimate
    The progress bar jumped around during a manual run. getPumpProgressLiters()
    preferred the sensor, but only returned it when the level delta was already
    positive — otherwise it fell through to elapsed time multiplied by the
    calibrated flow. Early in a run, or whenever noise nudged the delta the wrong
    way, the value flipped between a small measured number and a large estimated
    one. With the refill rate mis-calibrated at 19 L/min the estimate was wildly
    ahead, so the bar swung between nearly nothing and past full.
    Once the sensor is reporting it is now the only source: a delta that is not yet
    positive reads as ze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
    [WaterManager.cpp]
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2026-08-26 fix: shutdown paths now actually stop every pump, and cycles start clean
    Three related defects, all of which let an actuator keep running when the
    code said it had been stopped.
    allPumpsOff() and pumpOff() wrote LOW to the pad. For the five dosing
    channels and the prime pump that is a no-op: once ledcAttachPin() routes a
    pad to the LEDC peripheral, digitalWrite() no longer reaches it, so an
    emergency shutdown left a dosing pump running at whatever duty it had.
    And the canister runs on an active-LOW SSR, so a blanket LOW across every
    output switched the filter ON at the exact moment everything was supposed
    to stop. Both paths now write the LEDC duty and the pad, without choosing
    between them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
    [Arduino.cpp, PumpLog.cpp, SafetyWatchdog.cpp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]
2026-08-26 fix: harden the HTTP body parser and the TPA trigger's assumptions
    Body handling. Fourteen POST handlers built their body with
    `String((char*)data).substring(0, len)`. The `data` buffer is not
    NUL-terminated, so the String constructor reads past its end until it
    happens to find a zero — a heap overread that pulls whatever follows in
    memory into the JSON parse, and can fault outright. The substring() then
    trimmed the result, which hid the symptom without preventing the read.
    Bodies also arrive in TCP-sized chunks, so parsing the first one alone
    silently acted on a truncated request. _collectBody() reassembles from the
    length, refuses anything over 4 KB with a 413 rather than buffering it,
    a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
    [Config.h, SafetyWatchdog.cpp, WaterManager.cpp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]
2026-08-26 fix: dosing no longer blocks the loop, and ferts wait for the water change
    doseChannel() switched a pump on and then sat in a delay() loop for the
    whole dose duration — up to 30 s for a fertiliser, 60 s for Prime. loop()
    did not run during that window, so the overflow watchdog, the emergency
    drain and the TPA state machine were all frozen while a pump was live.
    The delay(10) inside kept the hardware watchdog fed, which is why this
    never announced itself.
    startDose() now arms the pump and returns; tickDose() switches it off when
    the duration elapses, using a signed comparison so it stays correct across
    the millis() rollover. tickDose() runs above every early return in loop(),
    because maint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
    [FertManager.cpp, WaterManager.cpp, WaterManager.h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]
2026-08-26 fix: trilingual review — wiring contradiction, wrong API field, untranslated UI
    The safety-relevant one first. The Hardware Recommendations table in all
    three READMEs told the builder to wire an NC float in series with the
    refill pump's *power*. HARDWARE.md carries an explicit warning against
    exactly that: a reed contact is rated 0.5-1 A, the pump draws several amps
    at startup, and the contact arcs and eventually welds closed — a silent
    failure that voids the interlock without any symptom. The row also
    contradicted the row four lines above it in the same table, which already
    described the real device: a NO reed on the signal wire between GPIO33 and
    IN7. Rewritten in pt/en/ja to match the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
    [DisplayManager.cpp]
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
